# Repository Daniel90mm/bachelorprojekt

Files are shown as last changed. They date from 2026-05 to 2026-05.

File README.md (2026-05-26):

# Bachelorprojekt: Prototype Pulsoximeter

Repository til bachelorprojektets notebooks, måledata, referencedokumenter
og KiCad-hardwaredesign for en prototypisk pulsoximeter til ikke-invasiv
måling af arteriel iltmætning (SpO₂).

Systemet bruger to multipleksede LED'er ved 660 nm og 940 nm, en
Hamamatsu S1223 fotodiode og en analog signalkæde med transimpedans-
forstærker, andenordens Sallen-Key lavpasfilter og et ikke-inverterende
gain-trin. Det optiske interface er en modulær 3D-printet fingerklemme,
og signalindsamling og -behandling håndteres af en Analog Discovery 3
og en Python-pipeline baseret på ratio-of-ratios-metoden.

Den fulde rapport ligger som [thesis.pdf](thesis.pdf).

## Resultater (live demo)

- HR: (51.7 ± 0.3) BPM
- SpO₂: (95.8 ± 1.5) %: proof of concept, ikke klinisk kalibreret
- LED-bølgelængder: 664.99 nm (FWHM 18.30 nm) og 951.79 nm (FWHM 27.25 nm)

## Struktur

- [notebooks/](notebooks/): Jupyter-notebooks til analyse, plots, målinger og kalibrering.
- [data/](data/): måledata, kalibreringstabeller, livemålinger og genererede plots.
- [docs/](docs/): diagrammer og instrumentkalibrering brugt til dokumentation.
- [hardware/kicad/](hardware/kicad/): KiCad-printprojekt og produktionsfiler.
- [references/](references/): datablade og artikler brugt som projektreferencer.
- [thesis.pdf](thesis.pdf): den endelige rapport.

## Vigtige filer

- [notebooks/filtre.ipynb](notebooks/filtre.ipynb): Bode-analyse af LPF- og HPF-trin.
- [notebooks/plots.ipynb](notebooks/plots.ipynb): spektrale plots, LED-sammenligninger og projektfigurer.
- [notebooks/optokæde.ipynb](notebooks/optokæde.ipynb): simulering af hele optokæden fra LED til signal.
- [notebooks/hyperspektral_pixelanalyse.ipynb](notebooks/hyperspektral_pixelanalyse.ipynb): pixelanalyse af hyperspektrale .tif-billeder.
- [notebooks/spektrometer.ipynb](notebooks/spektrometer.ipynb): spektrometeranalyse.
- [notebooks/lineær_stage_kalibrering.ipynb](notebooks/lineær_stage_kalibrering.ipynb): kalibrering af lineær stage.
- [live_pulsoximeter_måling.py](live_pulsoximeter_måling.py): selvstændig liveprototype til måling af HR og SpO₂.
- [plot_pulsoximeter_målinger.py](plot_pulsoximeter_målinger.py): genererer rapportplots fra livemålingerne.
- [data/live/](data/live/): livemålinger brugt til rapportens demonstrationsplots.
- [data/calibration/](data/calibration/): kalibreringsdata og rå Bode-målinger.
- [data/plots/](data/plots/): eksportklare figurer til rapport og præsentation.
- [hardware/kicad/](hardware/kicad/): kredsløbsdiagram, PCB-layout og produktionsfiler.
- [references/datasheets/](references/datasheets/): datablade for centrale komponenter.

## Krav og installation

- Python 3.10 eller nyere.
- Digilent WaveForms SDK installeret (kræves af `dwfpy` for at tale med Discovery 3).

```bash
python -m venv .venv
source .venv/bin/activate    # Windows: .venv\Scripts\activate
pip install -r requirements.txt
```

## Live pulsoximeter

Kør livevisning med popout-plot:

```bash
python live_pulsoximeter_måling.py --cycle-rate 7.41
```

Regenerer rapportplots fra livemålingerne i [data/live/](data/live/):

```bash
python plot_pulsoximeter_målinger.py
```

## Noter

- Lokale editorfiler, Jupyter-cache, KiCad-låse-/historikfiler og genererede backup-zipfiler ignoreres.
- Løse WaveForms-eksporter og rå livemålinger i repo-roden ignoreres.
  Rå kalibreringsmålinger ligger i [data/calibration/](data/calibration/),
  navngivne livemålinger i [data/live/](data/live/), og færdige figurer
  ligger i [data/plots/](data/plots/).

## Licens

MIT: se [LICENSE](LICENSE).

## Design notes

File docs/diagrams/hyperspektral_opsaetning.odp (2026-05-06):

## Hyperspektralt setup, formål og rolle I projekt

- Validere valg af bølgelængder til analogt setup
- Relativt transmitteret intensitet per bølgelængde → pixel intensitet

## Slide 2

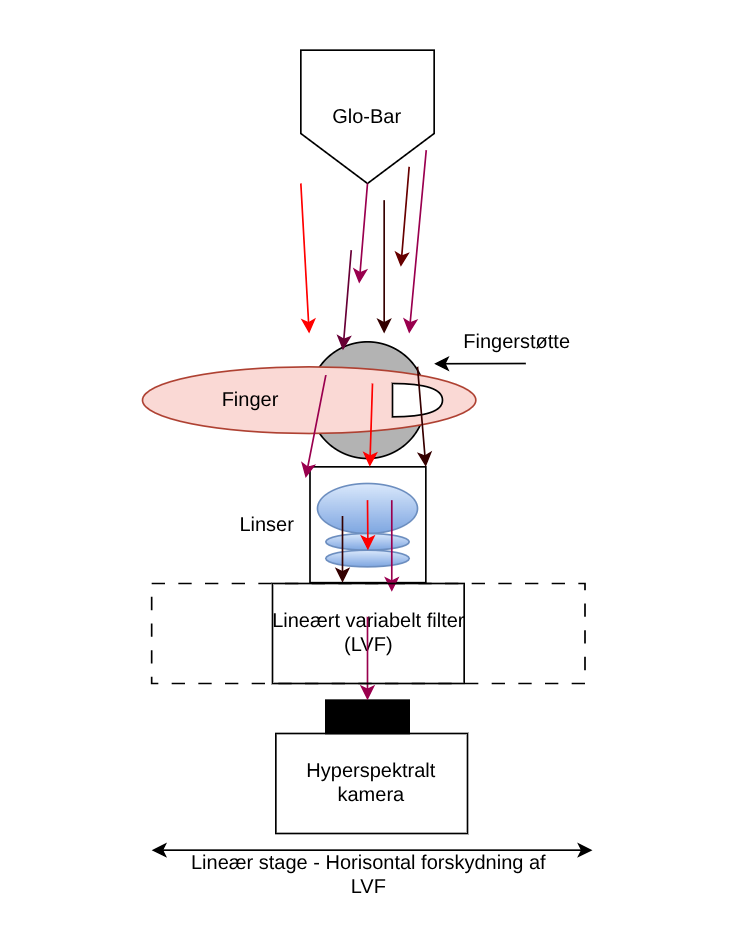
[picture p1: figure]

Glo-Bar:

- Bredbåndet kilde
- Sort legeme spektrum med spektral irradians I NIR(800-1100nm)
- Peak ved mid-IR(1900-2400nm)

LVF, lineært variabelt filter:

- ~800-1100nm
- FWHM skalerer med bølgelængde
- Bandpasser bølgelængder

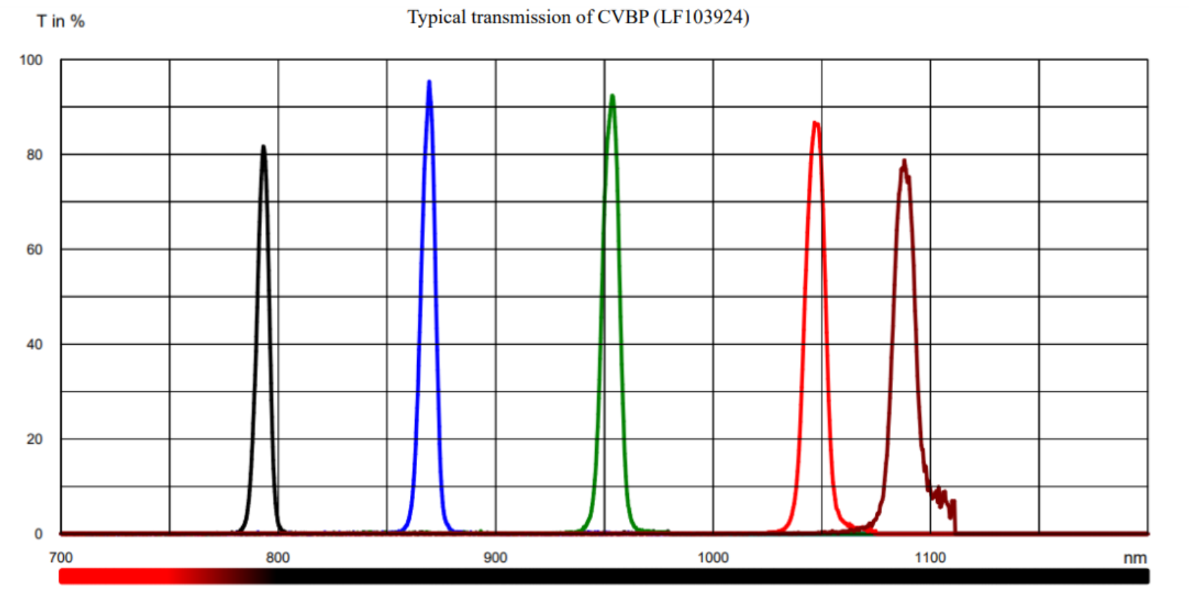
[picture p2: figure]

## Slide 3

- Spredning dominerer over absorption I NIR I væv
- Pga. Spredning, rejser fotoner 4-7 gange længere end fingerafstand d.
  Kvantificeret med DPF (differential pathlength factor)

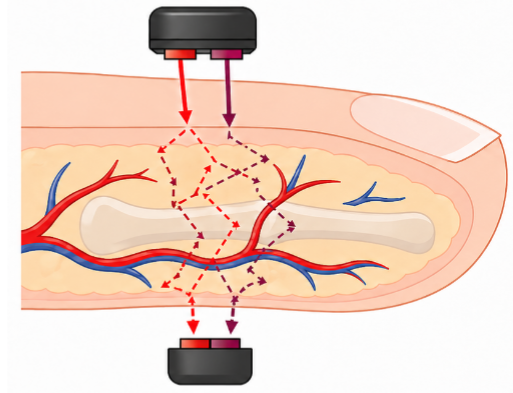
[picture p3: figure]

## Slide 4

Kamera:

- Kvante effektivitet per bølgelængde
- Silicium sensor, NIR variant
- Længere integrationstid → Flere fotoner opsamles → Højere pixelværdi indtil mættelse
- Foton → elektron hul-par → ADC “fyldes op” → Hvidere pixel I kamera feed
- Kameraet skelner ikke mellem bølgelængder, det gør LVF
- Mørkemåling tages med fikseret interesseregion (ROI) og integrationstid
- Faktisk måling tages med samme ROI & integrationstid
- Median udregnes af mørkemåling og faktisk måling
- Korrigeret_måling(ƛ) = median[måling(ƛ)] – median[mørkemåling(ƛ)]
- Hyperspekt_output(ƛ) = Korrigeret_måling(ƛ) / integrationstid

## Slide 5

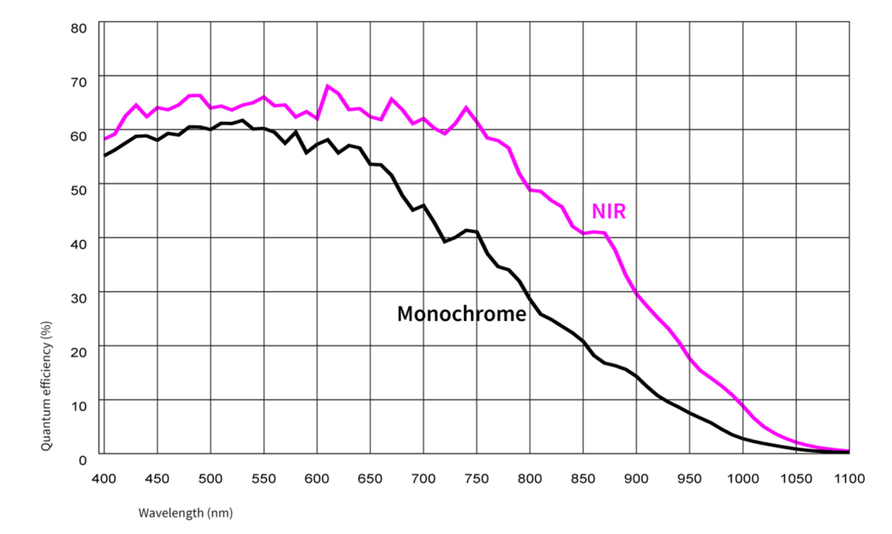
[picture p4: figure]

~47%

~22%

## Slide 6

Resultater

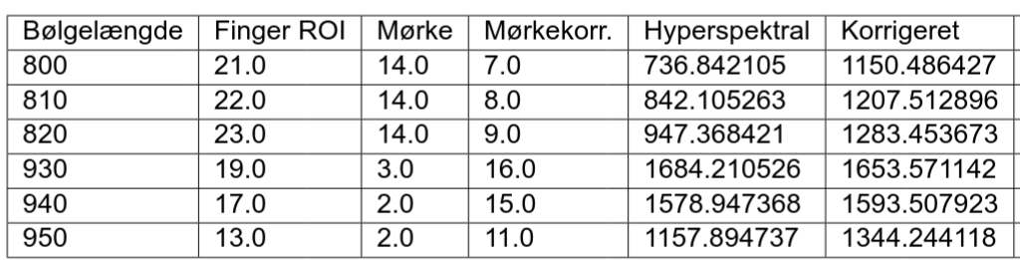
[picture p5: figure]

Korrigeret for datasheet specs med diverse
attenuationer per bølgelængde

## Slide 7

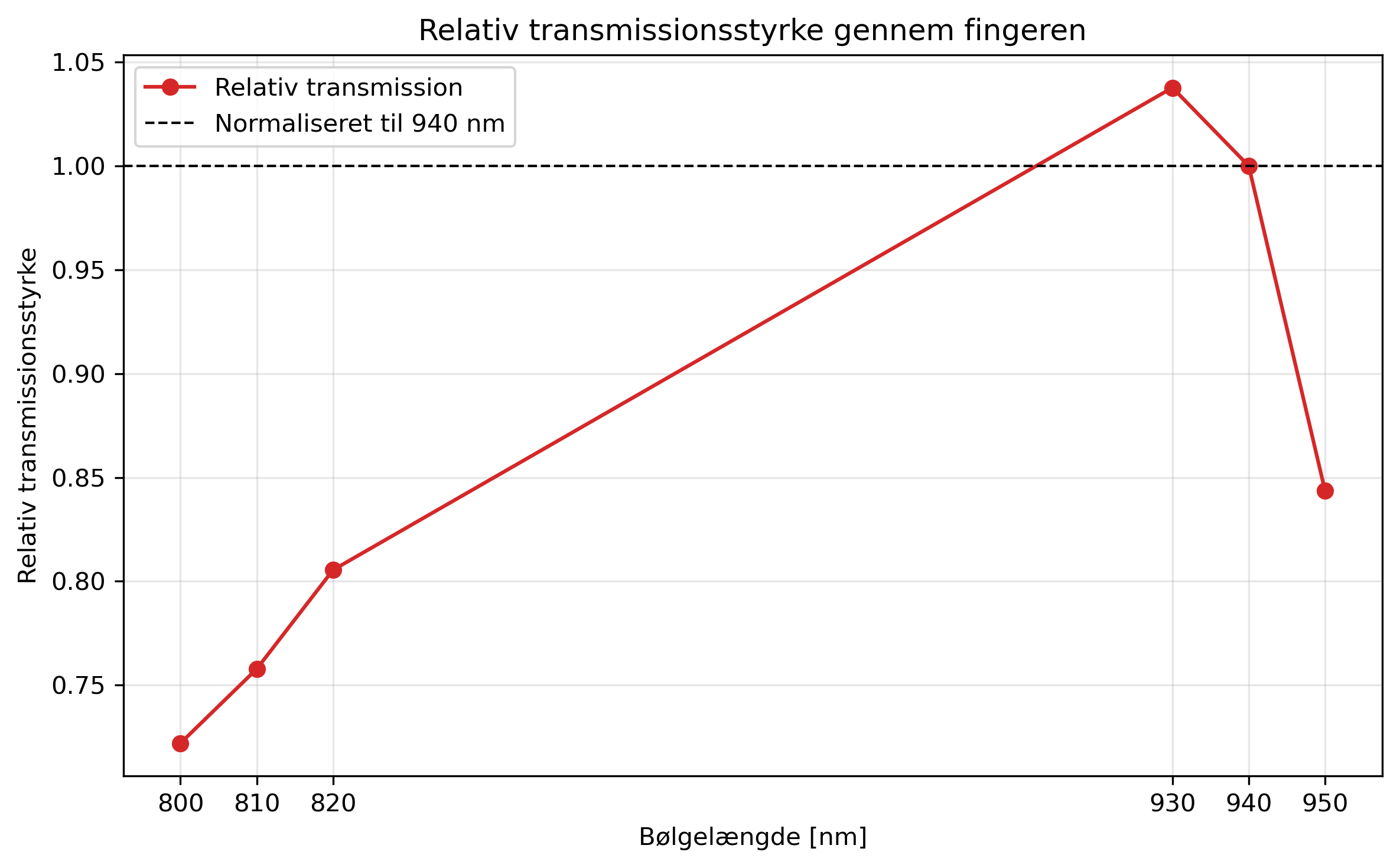
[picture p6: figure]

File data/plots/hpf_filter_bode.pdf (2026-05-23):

### Højpasfilter: målt frekvensrespons

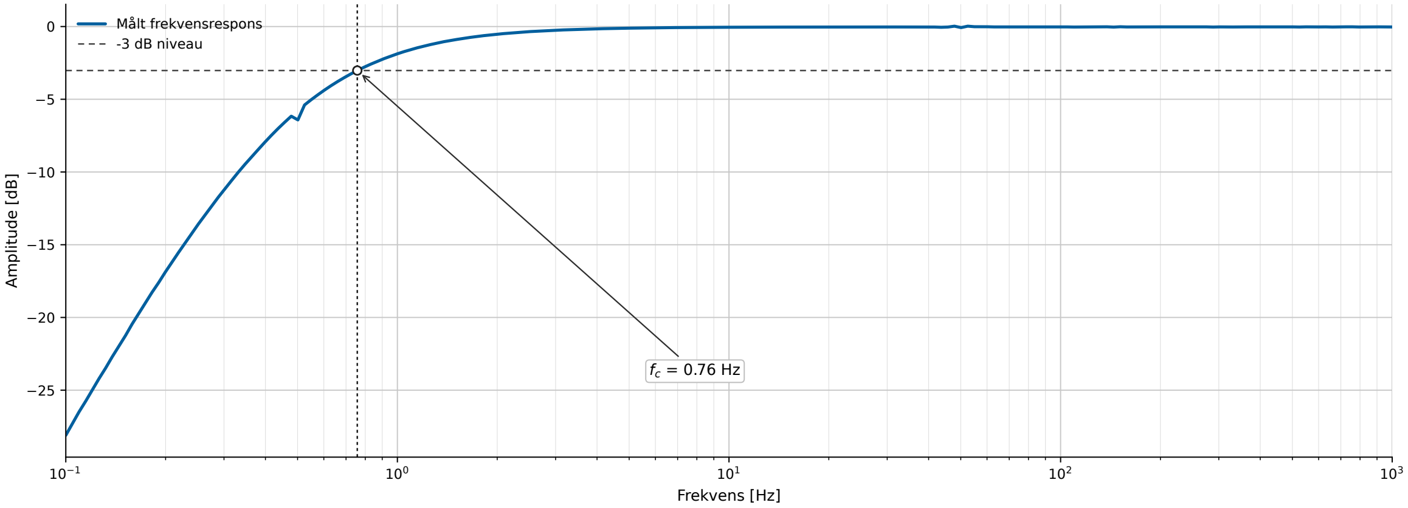
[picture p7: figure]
Frekvens [Hz]; Amplitude [dB]; Målt frekvensrespons -3 dB niveau

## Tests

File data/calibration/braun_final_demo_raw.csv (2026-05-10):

v_660 | v_940 | v_dark | v_660_korr | v_940_korr | t_s
3.8659478658159014 | 4.352355155628666 | 0.009007681549563657 | 3.856940184266338 | 4.343347474079102 | 0.5520272519788705
3.9043274512252446 | 4.376674222711291 | 0.009022347901023764 | 3.8953051033242208 | 4.367651874810267 | 0.7000380189856514
4.001045270019376 | 4.432150261199594 | 0.008407489320580708 | 3.9926377806987956 | 4.423742771879014 | 0.9922793039877433
3.8210158058465344 | 4.293303911926739 | 0.010386318586813936 | 3.8106294872597206 | 4.282917593339925 | 1.2256143789854832
3.8156682284680024 | 4.300710419414095 | 0.010613082944004848 | 3.8050551455239976 | 4.29009733647009 | 1.4984336989873555
3.882745350961253 | 4.345723708406934 | 0.010631133838109605 | 3.8721142171231433 | 4.335092574568824 | 1.7334016989916563
3.96838781804124 | 4.394711578645461 | 0.010974100826099856 | 3.95741371721514 | 4.383737477819362 | 1.9846574179828167
4.0455632876052166 | 4.435411832128148 | 0.011618292109463137 | 4.033944995495753 | 4.423793540018685 | 2.2000456949754152
3.8901349357353854 | 4.30695038786993 | 0.010517187569073366 | 3.879617748166312 | 4.296433200300856 | 2.443767716991715
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

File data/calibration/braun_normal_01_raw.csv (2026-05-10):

v_660 | v_940 | v_dark | v_660_korr | v_940_korr | t_s
2.846700745648549 | 3.1698681591676507 | 0.03204400696986929 | 2.81465673867868 | 3.1378241521977817 | 0.5542634270095732
2.88233659515397 | 3.190915501693789 | 0.03210380055659126 | 2.8502327945973787 | 3.1588117011371977 | 0.703124221006874
2.69107721848621 | 3.042041880745746 | 0.03134227846154713 | 2.659734940024663 | 3.0106996022841988 | 0.985604036017321
2.731528143994073 | 3.078389612387423 | 0.031414482037966124 | 2.700113661956107 | 3.0469751303494568 | 1.234539452008903
2.804102891923102 | 3.1245773376779518 | 0.031944727052293155 | 2.7721581648708087 | 3.0926326106256585 | 1.4933193490142003
2.8651419903383144 | 3.161053681940125 | 0.03186913893322952 | 2.8332728514050847 | 3.1291845430068954 | 1.711352947022533
2.93088785939134 | 3.2016557836861157 | 0.032196311388878116 | 2.898691548002462 | 3.1694594722972376 | 1.942395899008261
2.8414862936140395 | 3.097546123756089 | 0.032556201090091566 | 2.8089300925239478 | 3.064989922665997 | 2.157126000005519
2.813807503866168 | 3.104280235438042 | 0.03220872137857513 | 2.7815987824875927 | 3.0720715140594668 | 2.3972083250118885
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

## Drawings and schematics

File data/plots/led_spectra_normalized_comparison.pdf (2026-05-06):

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

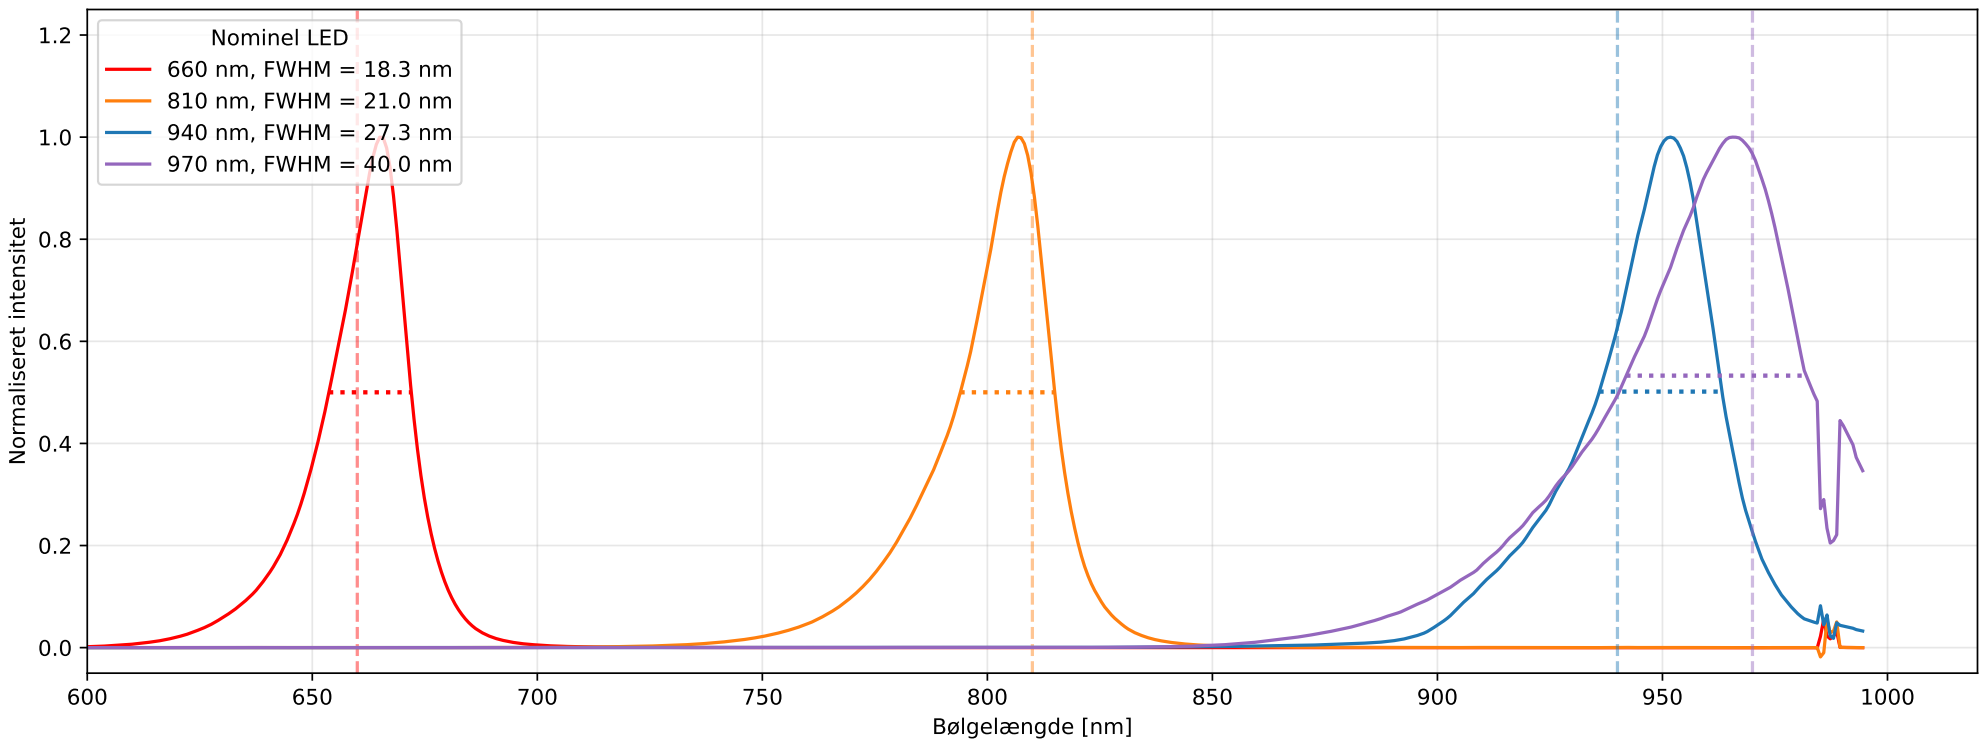
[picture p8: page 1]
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

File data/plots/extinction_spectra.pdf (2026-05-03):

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

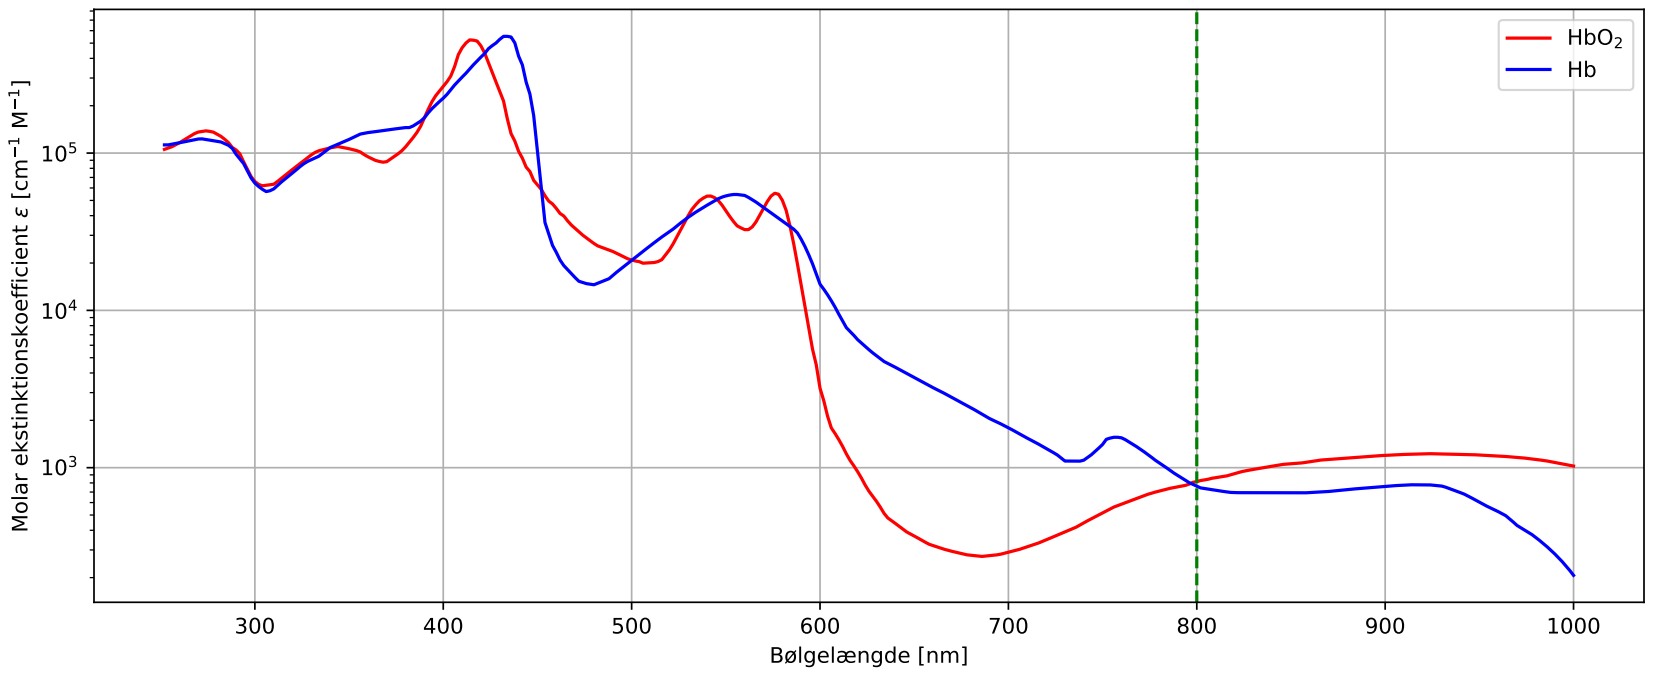
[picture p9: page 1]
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

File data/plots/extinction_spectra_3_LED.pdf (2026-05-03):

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

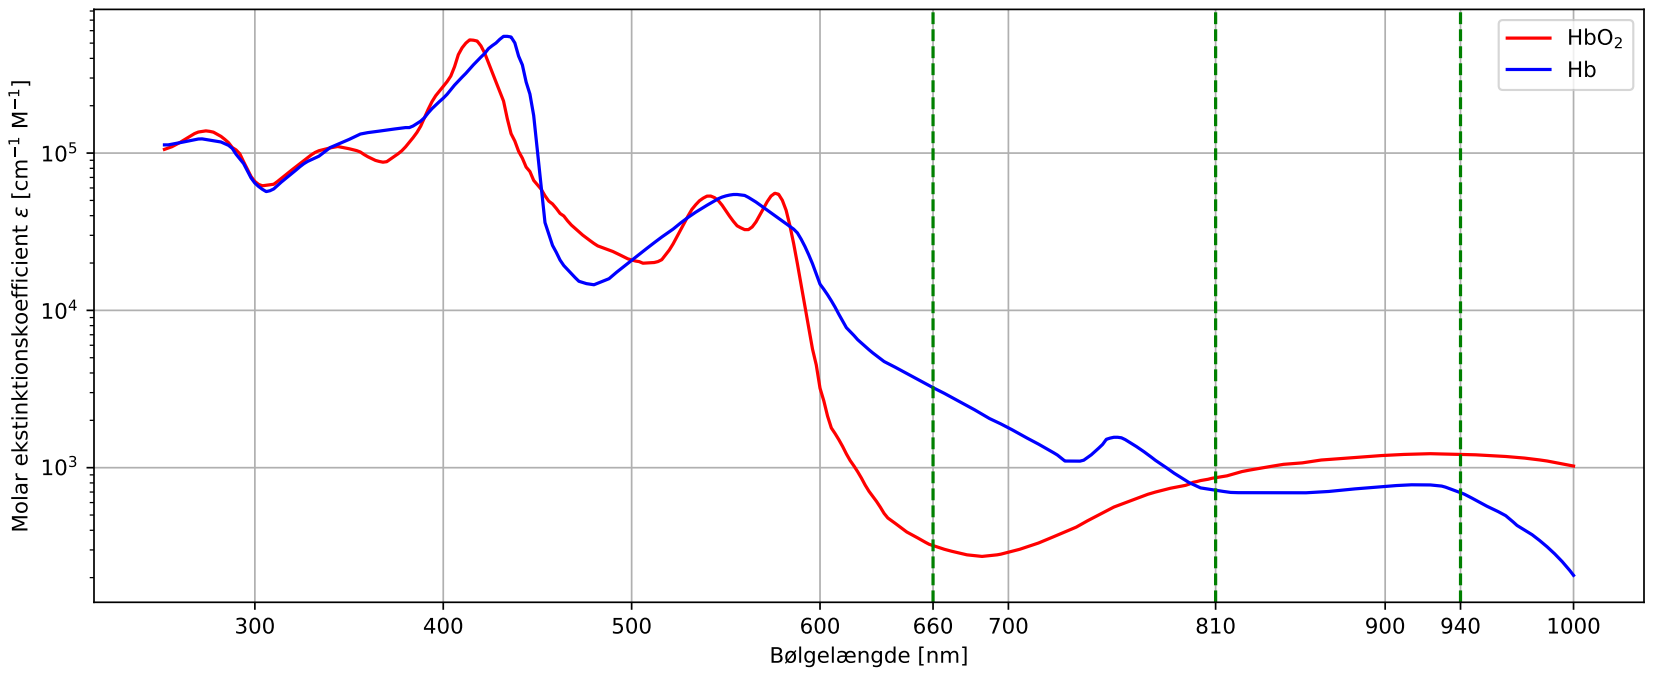
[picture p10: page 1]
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

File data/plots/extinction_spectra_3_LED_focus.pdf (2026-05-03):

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

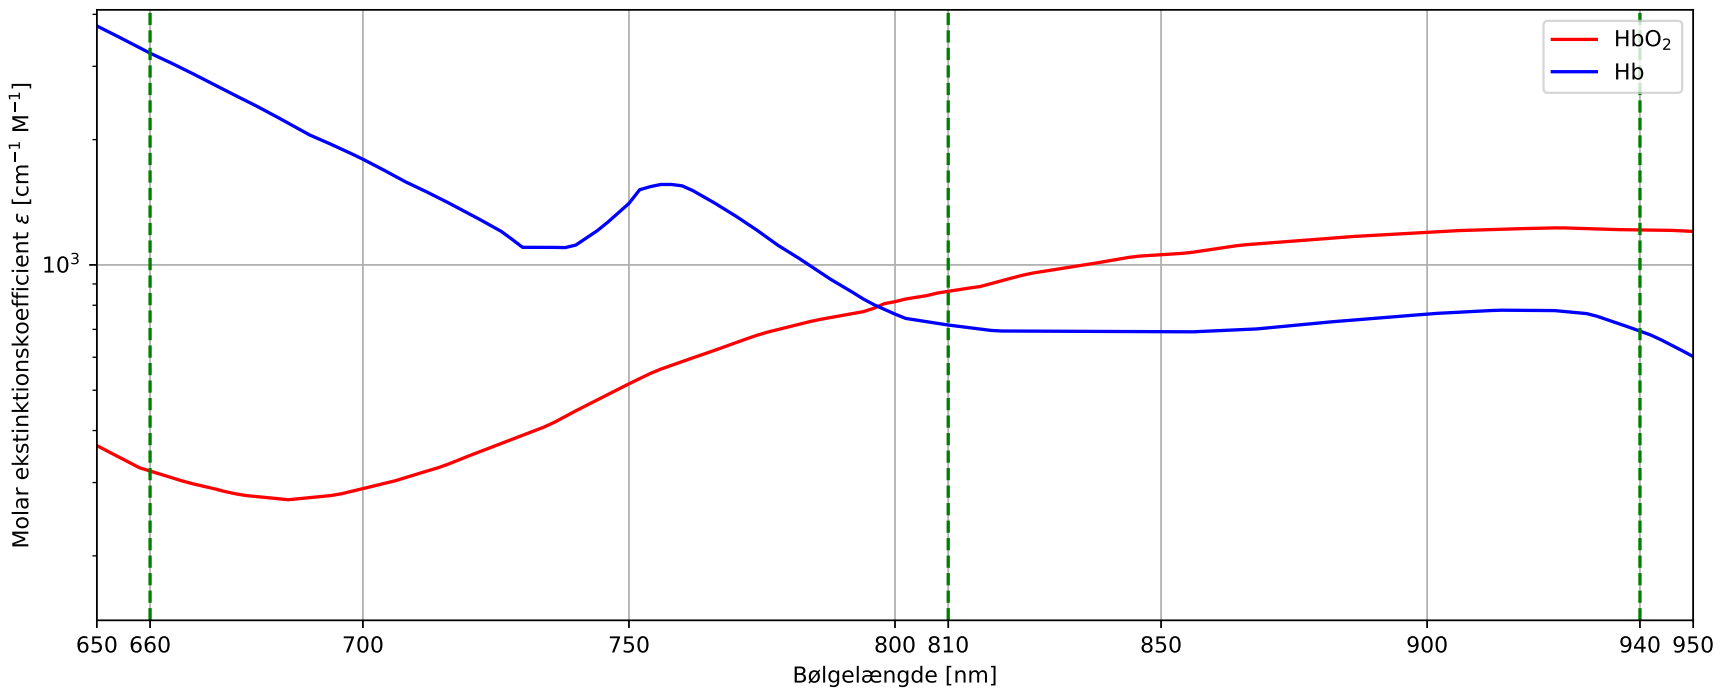
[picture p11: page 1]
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

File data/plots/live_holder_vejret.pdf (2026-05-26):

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

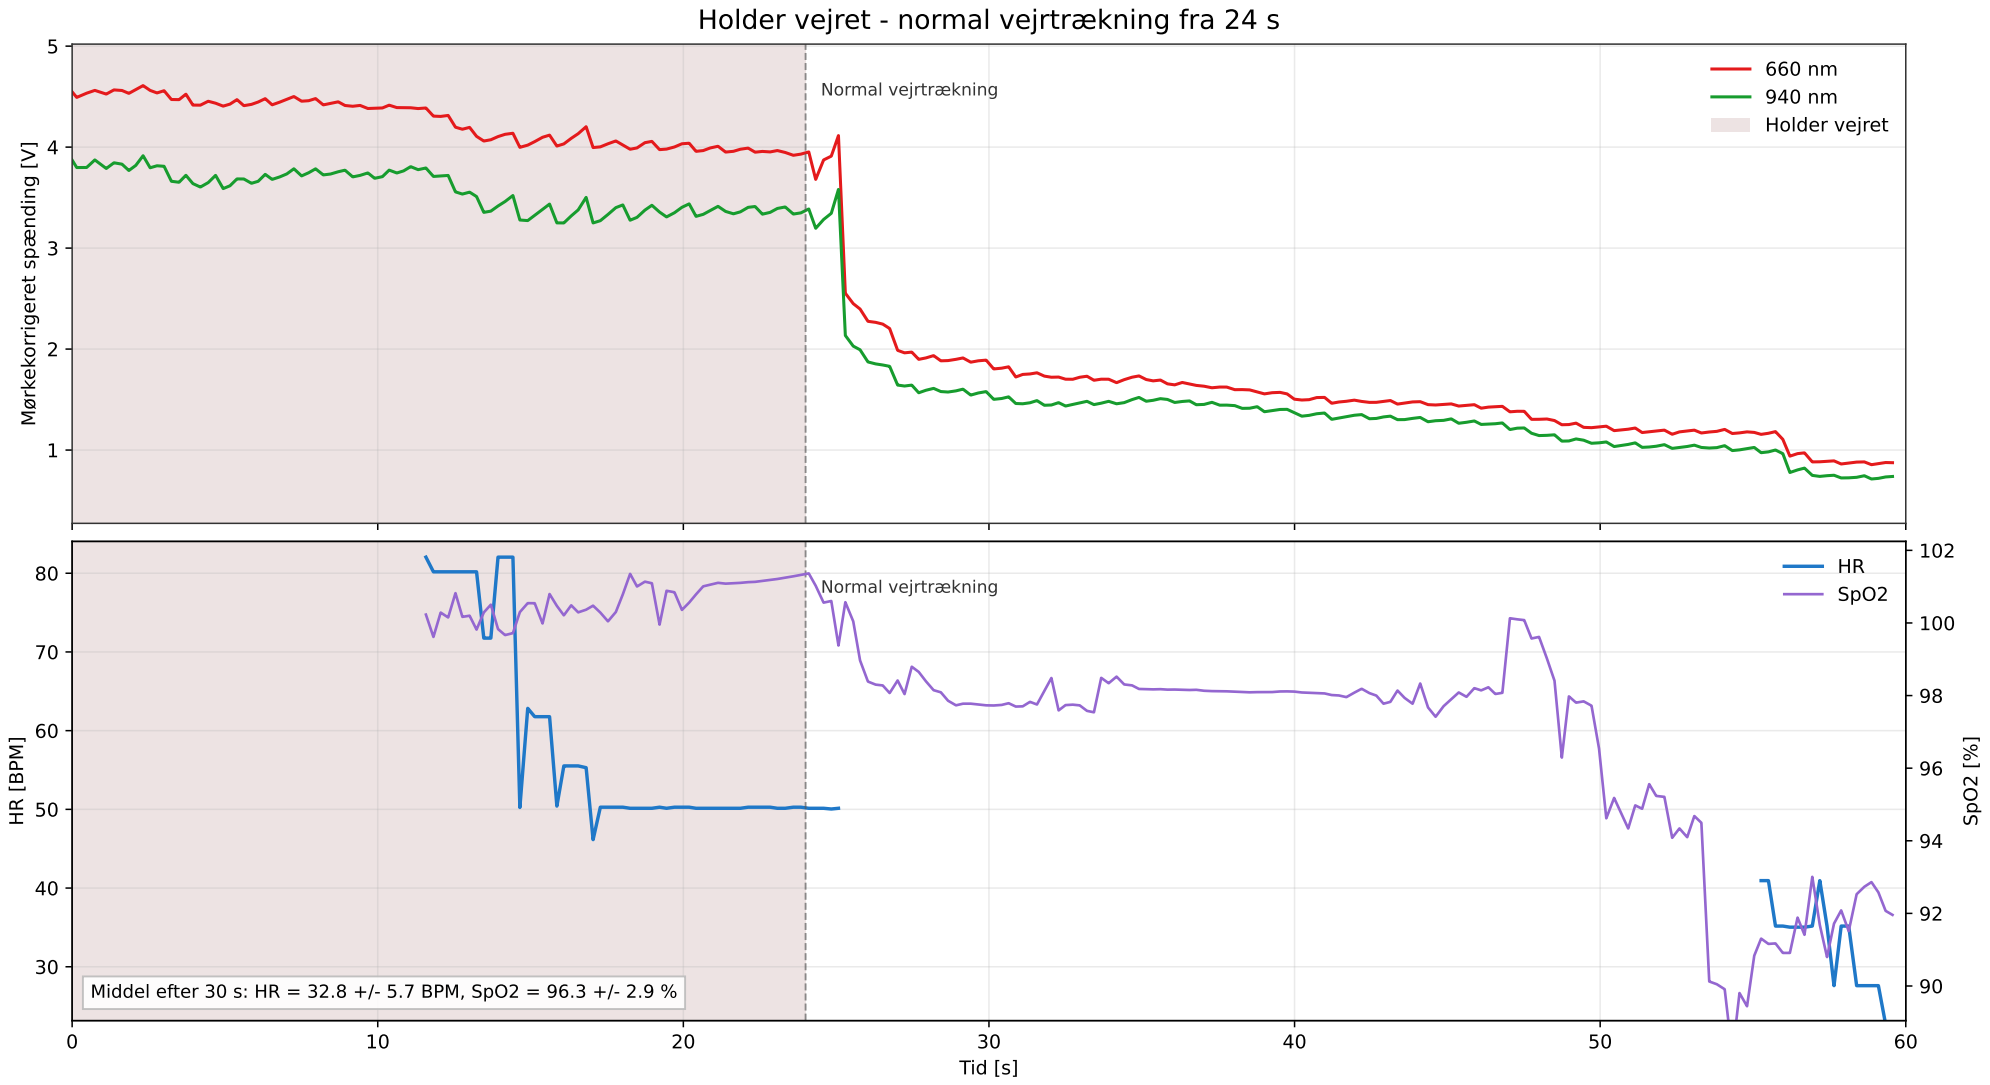
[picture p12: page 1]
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

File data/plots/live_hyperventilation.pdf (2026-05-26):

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

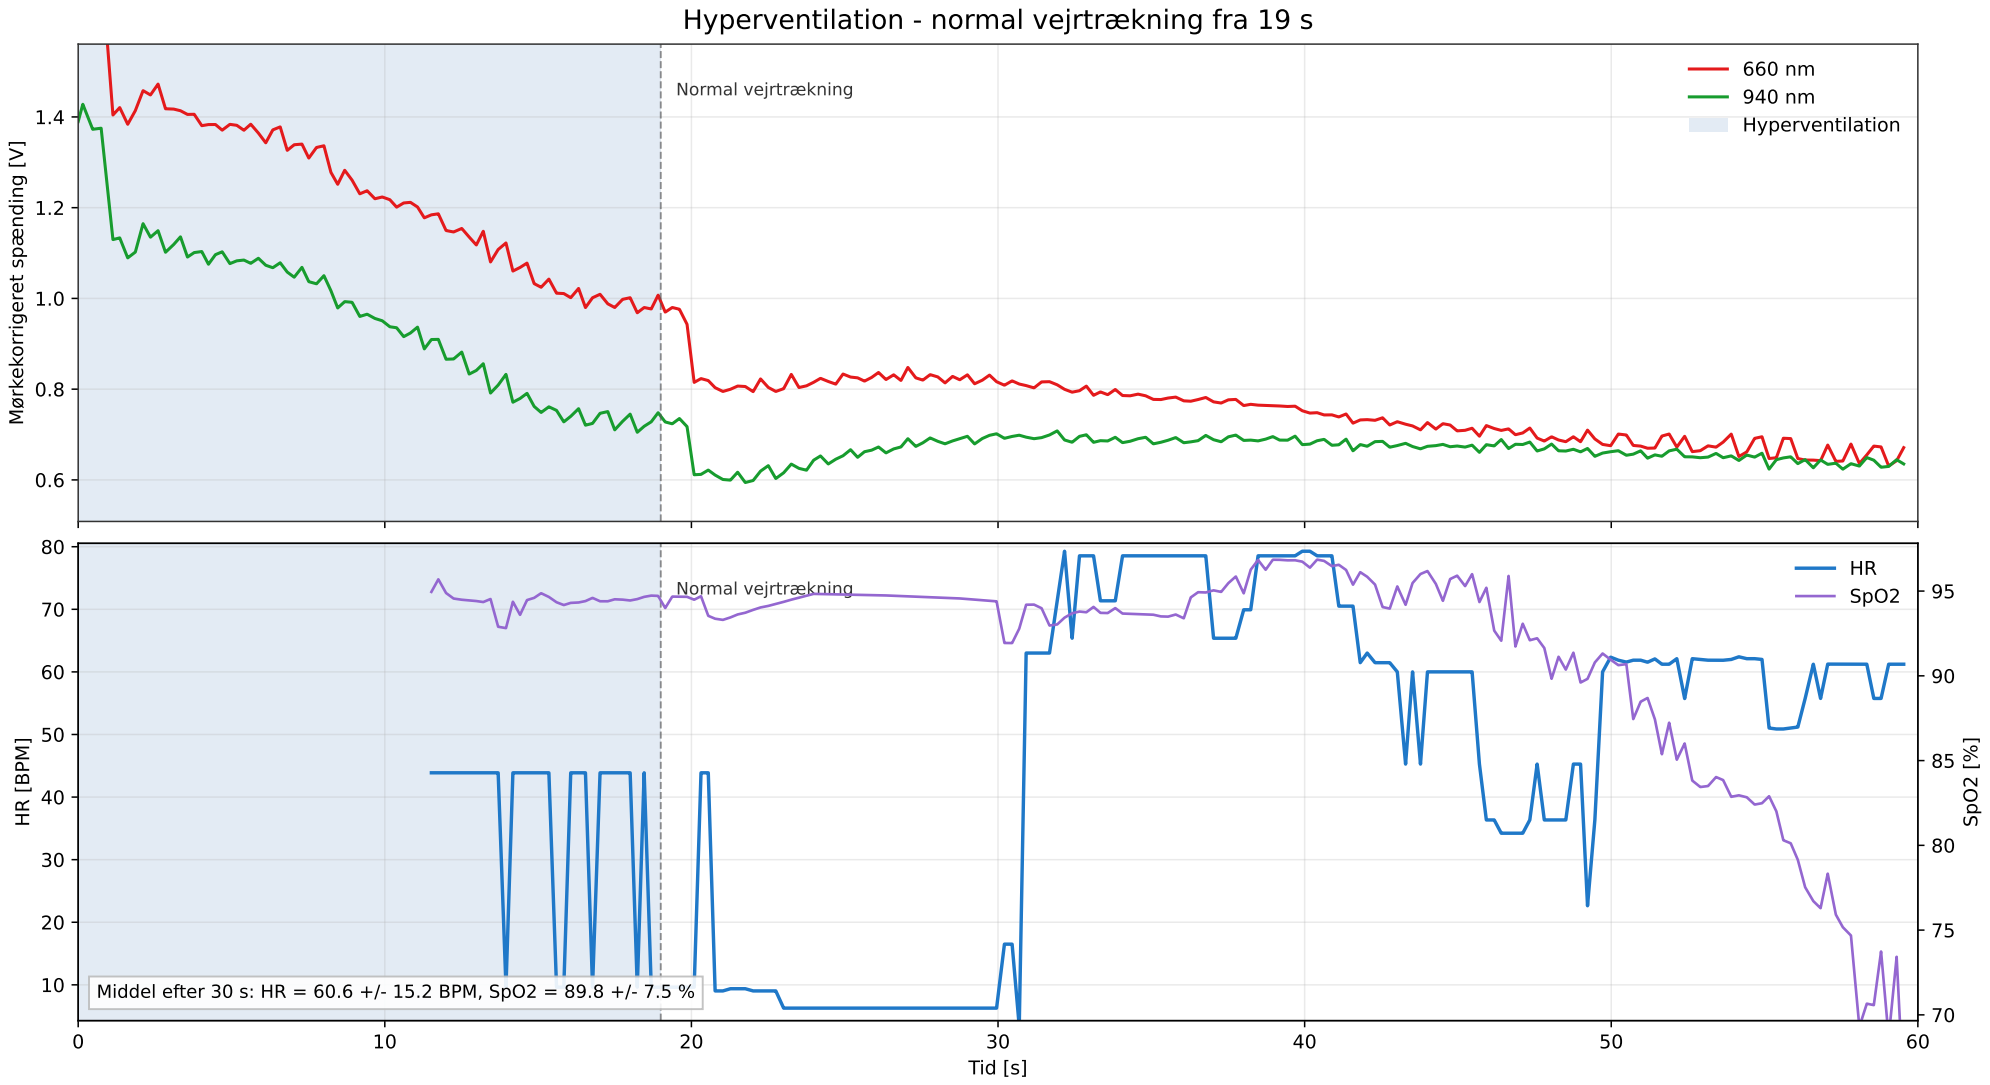
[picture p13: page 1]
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

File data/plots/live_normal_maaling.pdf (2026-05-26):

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

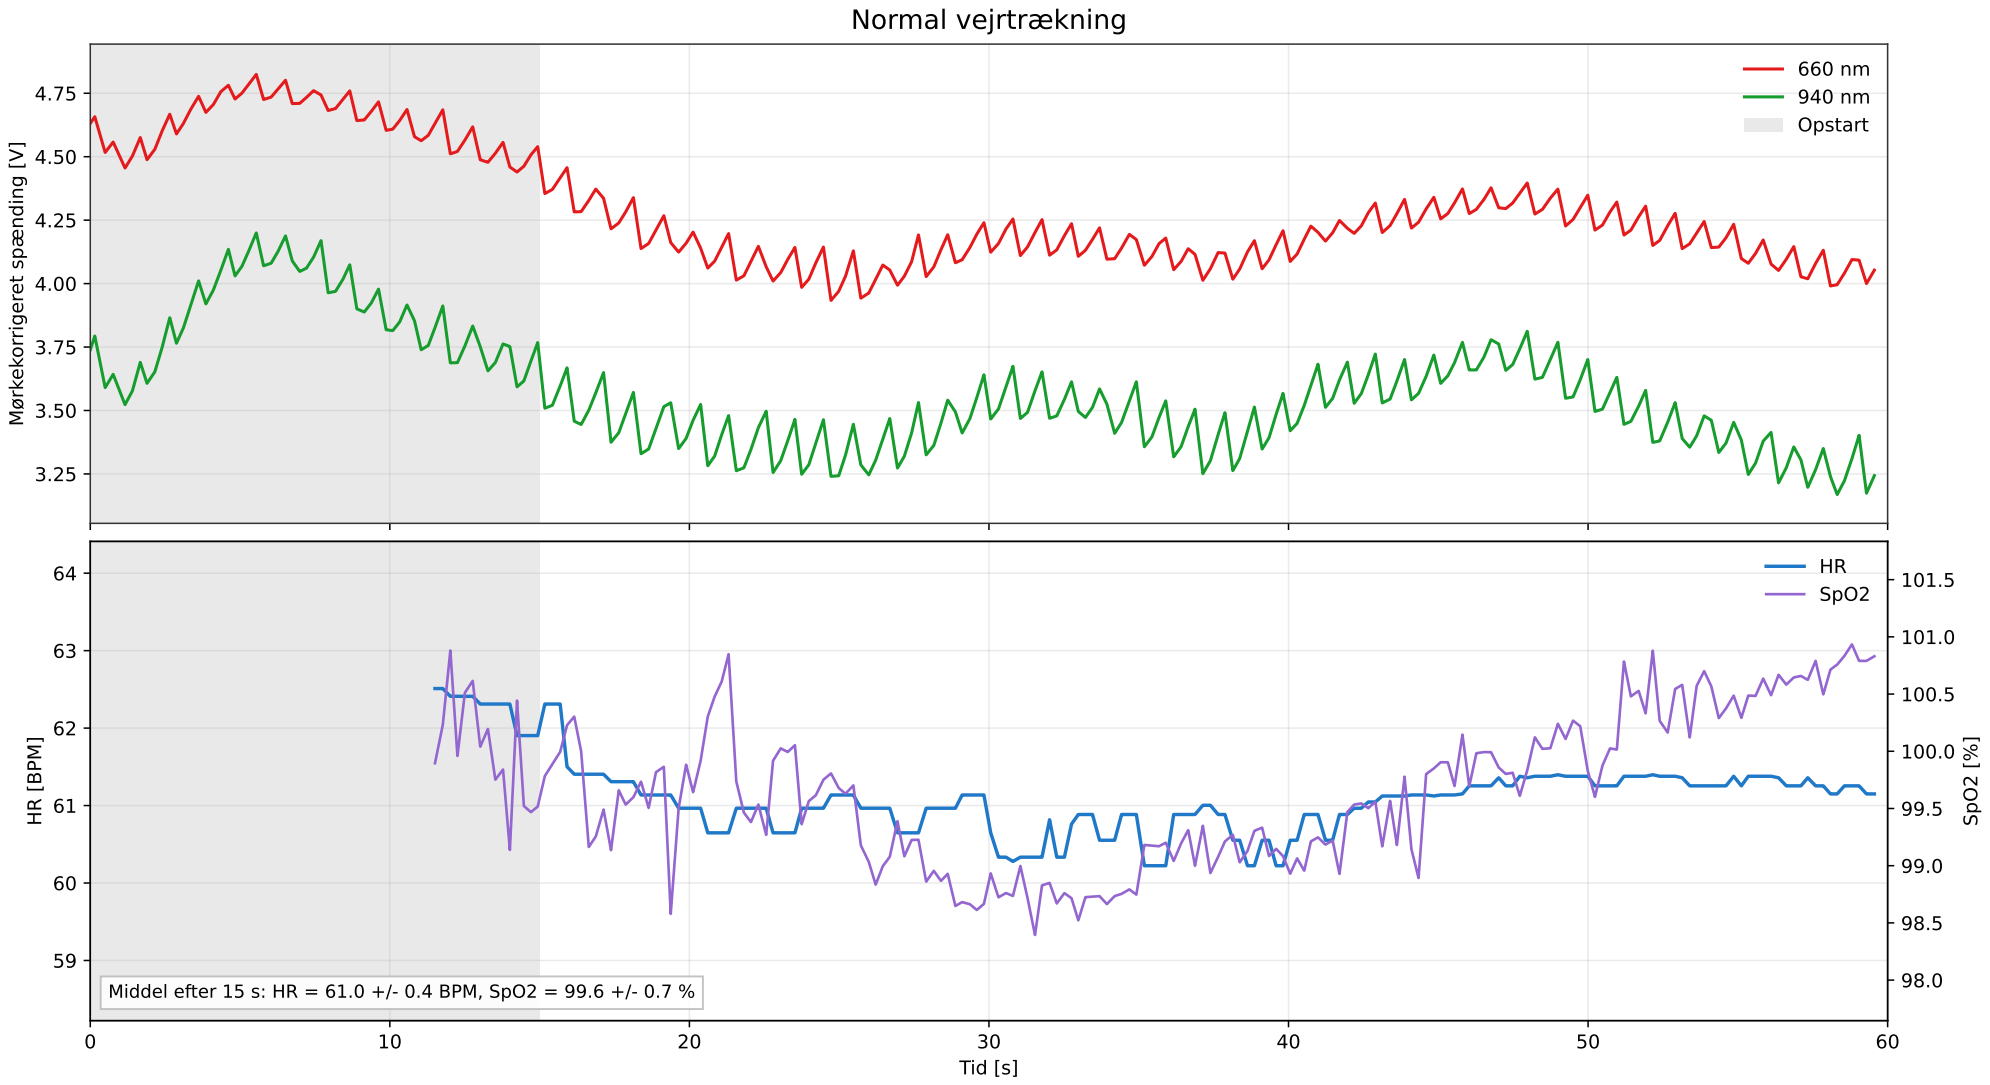
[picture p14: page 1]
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

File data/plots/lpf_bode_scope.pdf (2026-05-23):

−100

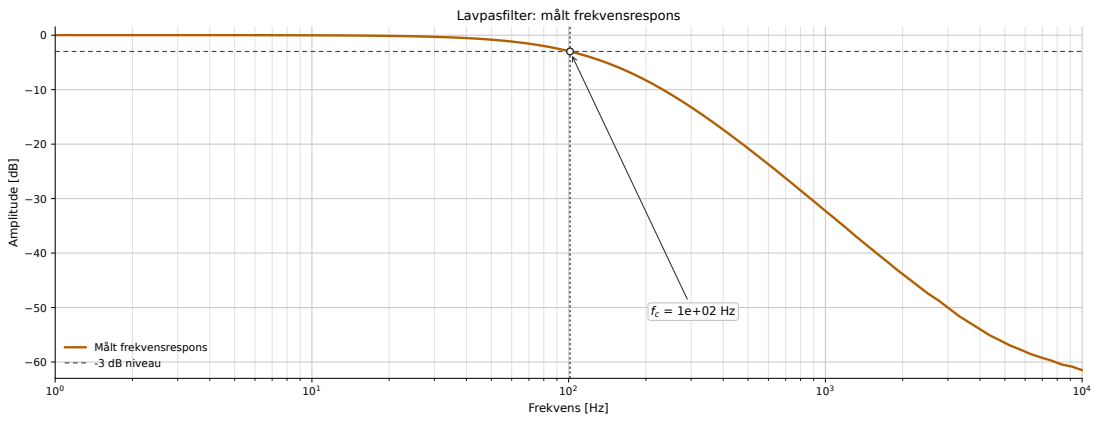
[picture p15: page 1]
Frekvens [Hz]; Amplitude [dB]; Målt frekvensrespons -3 dB niveau

Lavpasfilter: målt frekvensrespons

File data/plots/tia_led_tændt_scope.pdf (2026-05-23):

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

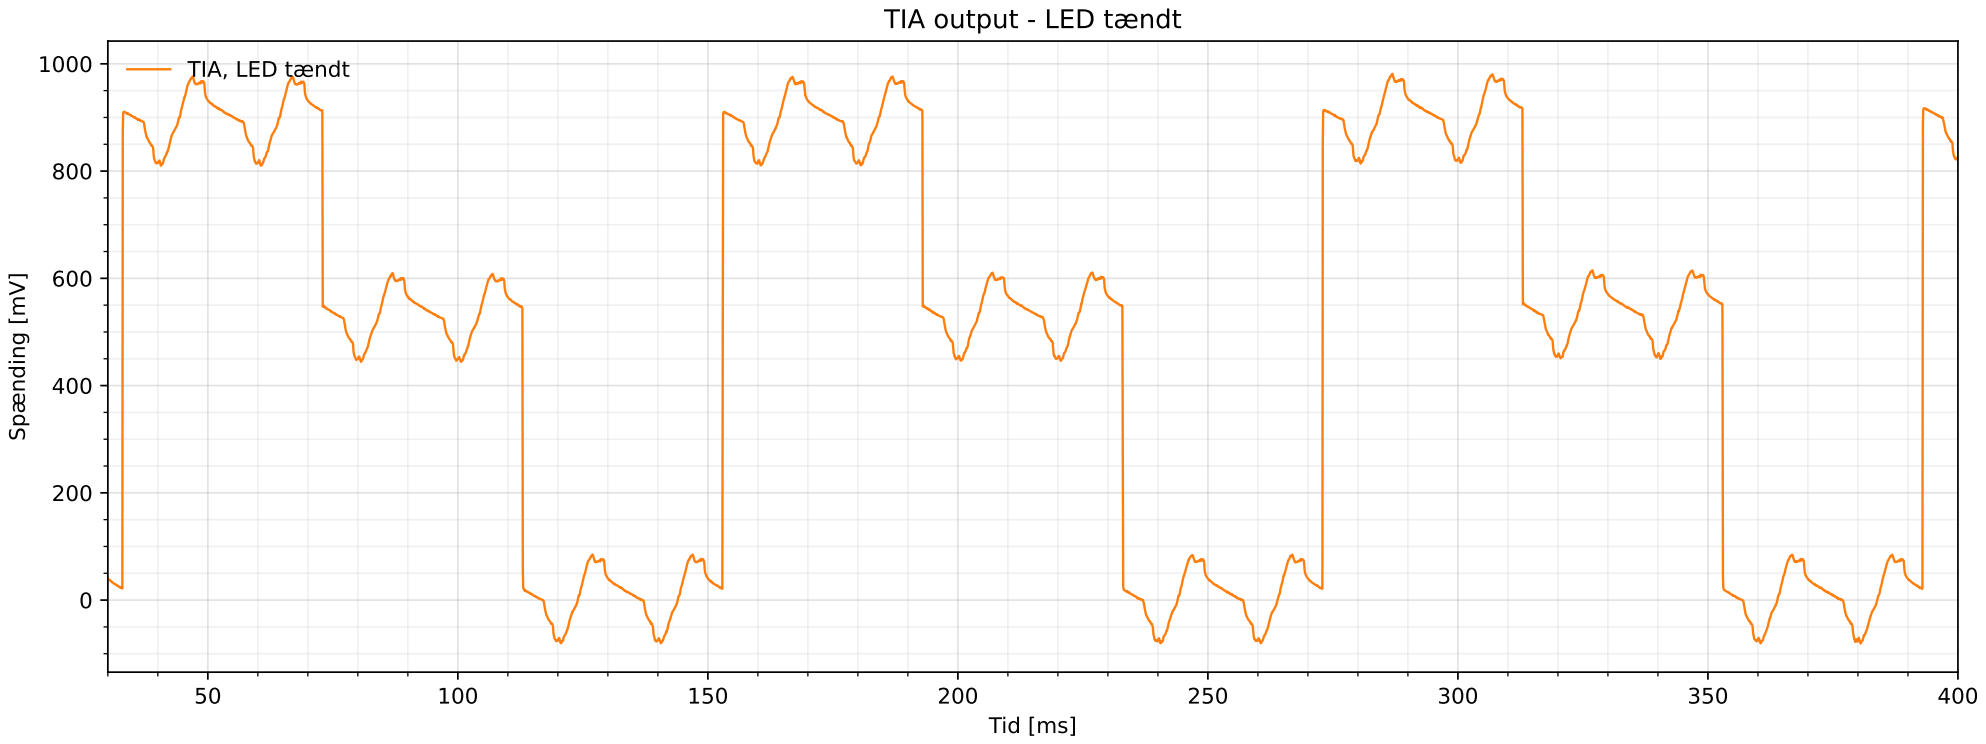
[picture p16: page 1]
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

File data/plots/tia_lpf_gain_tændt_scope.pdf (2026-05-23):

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

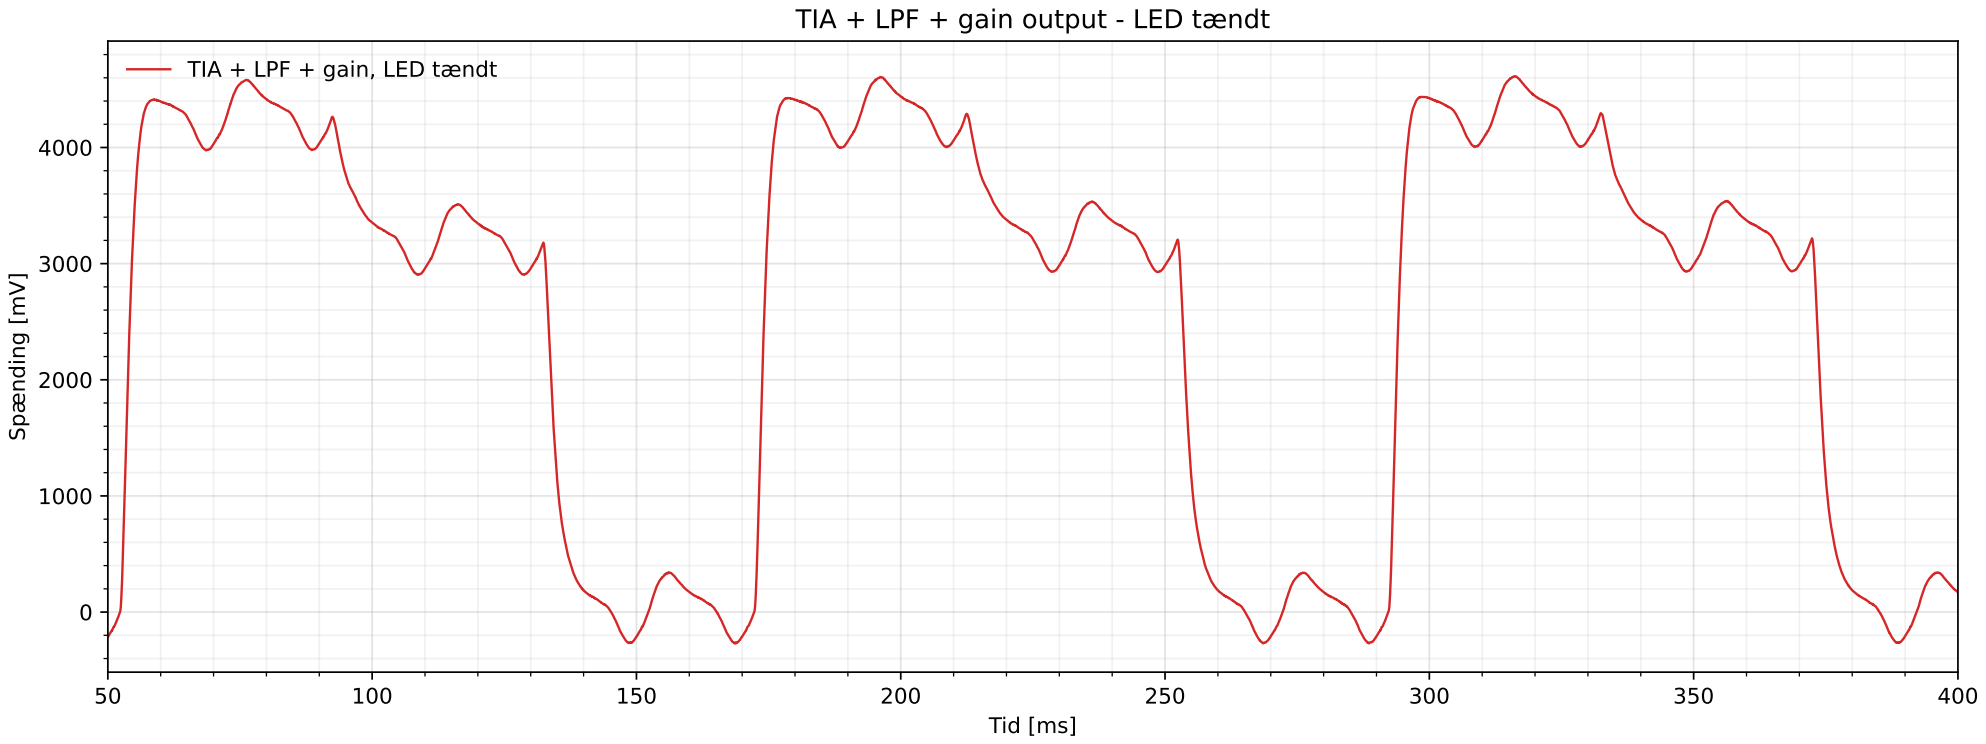
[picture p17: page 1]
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

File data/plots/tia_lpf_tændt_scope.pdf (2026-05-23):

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

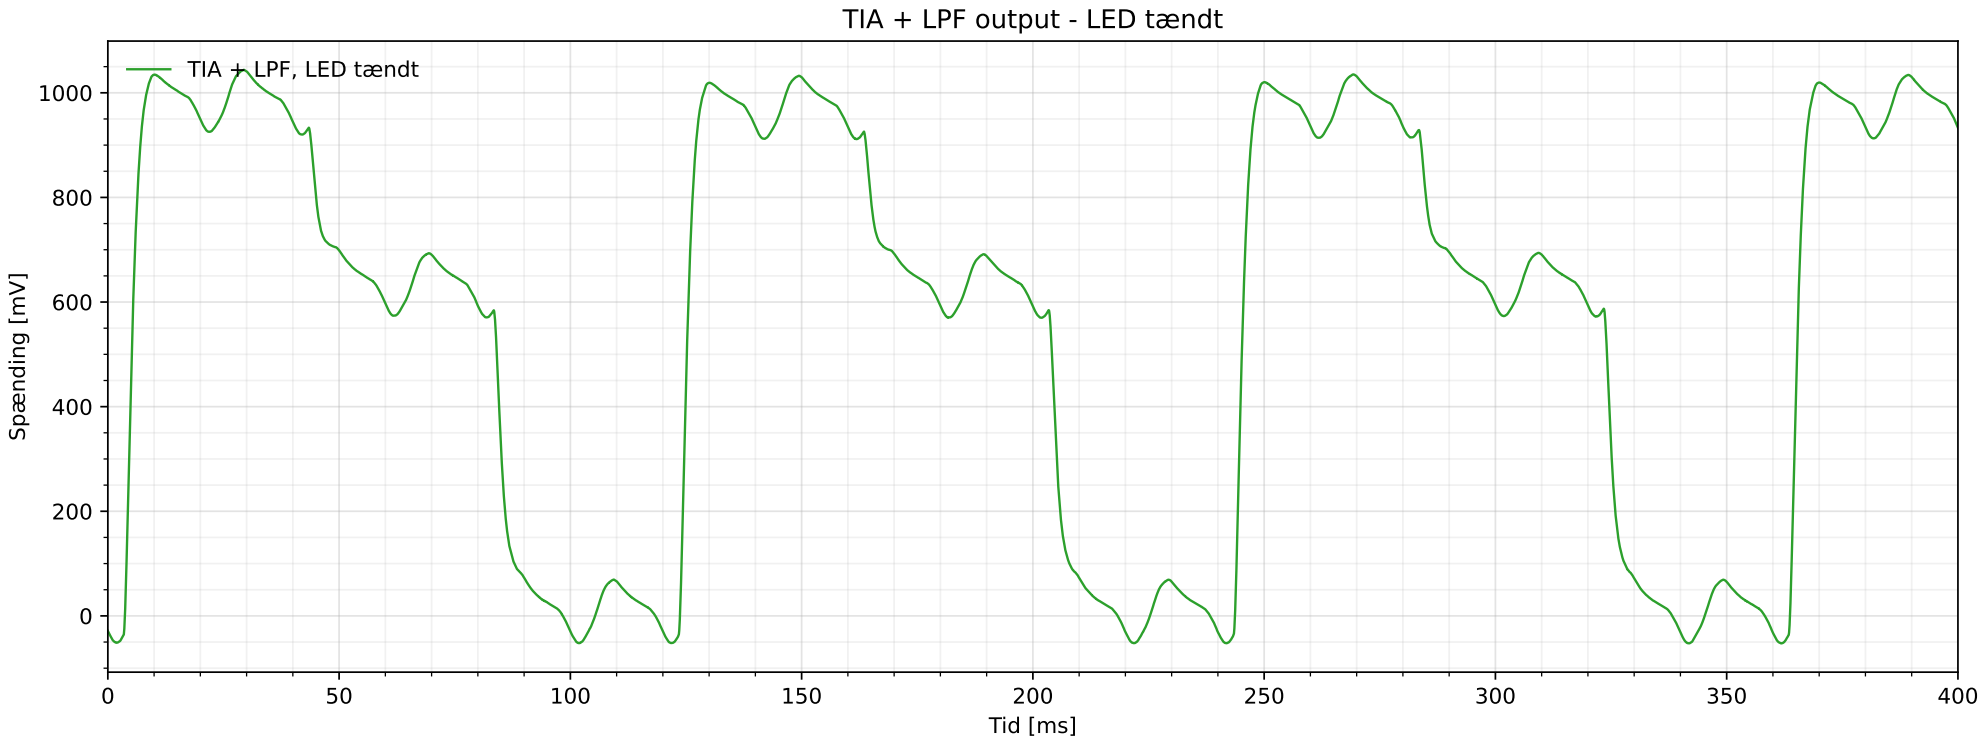
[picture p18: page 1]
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

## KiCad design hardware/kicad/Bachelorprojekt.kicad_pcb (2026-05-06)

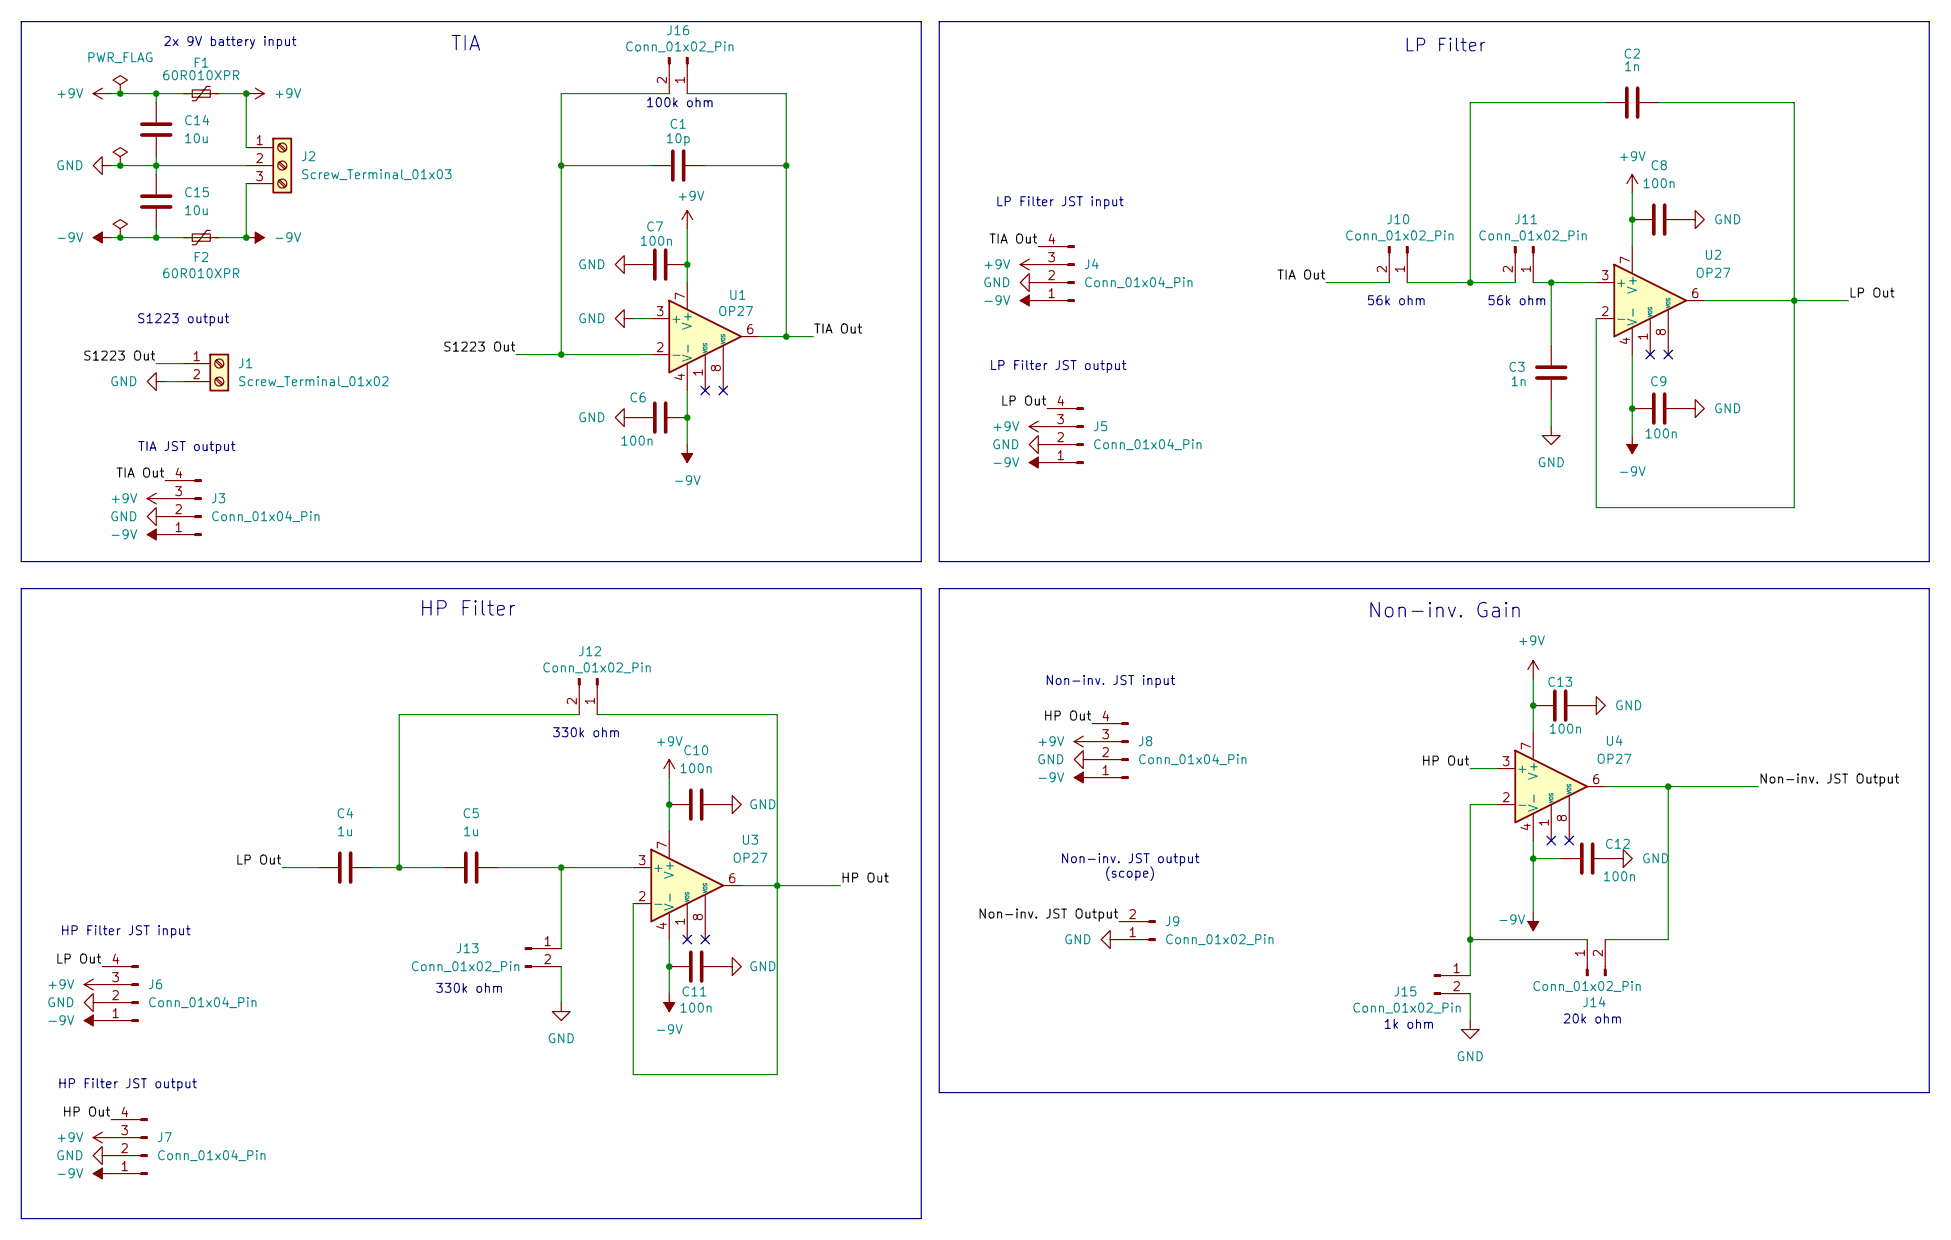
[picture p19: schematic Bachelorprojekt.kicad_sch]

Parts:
C1: 10p; C_Disc_D5.0mm_W2.5mm_P2.50mm
C2, C3: 1n; C_Rect_L7.0mm_W3.5mm_P5.00mm
C4, C5: 1u; C_Rect_L7.2mm_W7.2mm_P5.00mm_FKS2_FKP2_MKS2_MKP2
C6, C7, C8, C9, C10, C11, C12, C13: 100n; C_Rect_L7.0mm_W3.5mm_P5.00mm
C14, C15: 10u; C_Rect_L7.0mm_W4.5mm_P5.00mm
F1, F2: 60R010XPR; Fuse_Bourns_MF-RG300
J1: Screw_Terminal_01x02; TerminalBlock_MaiXu_MX126-5.0-02P_1x02_P5.00mm
J2: Screw_Terminal_01x03; TerminalBlock_MaiXu_MX126-5.0-03P_1x03_P5.00mm
J3, J4, J5, J6, J7, J8: Conn_01x04_Pin; JST_XH_B4B-XH-A_1x04_P2.50mm_Vertical
J9: Conn_01x02_Pin; JST_XH_B2B-XH-A_1x02_P2.50mm_Vertical
J10, J11, J12, J13, J14, J15, J16: Conn_01x02_Pin; PinSocket_1x02_P2.54mm_Vertical
U1, U2, U3, U4: OP27; DIP-8_W7.62mm_Socket

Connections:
+9V: C7.2, C8.1, C10.1, C13.1, C14.1, F1.1, F1.2, J2.1, J3.3, J4.3, J5.3, J6.3, J7.3, J8.3, U1.7 (V+), U2.7 (V+), U3.7 (V+), U4.7 (V+)
-9V: C6.2, C9.1, C11.1, C12.1, C15.2, F2.1, F2.2, J2.3, J3.1, J4.1, J5.1, J6.1, J7.1, J8.1, U1.4 (V-), U2.4 (V-), U3.4 (V-), U4.4 (V-)
/HP Out: J7.4, J8.4, J12.1, U3.2 (-), U3.6, U4.3 (+)
/LP Out: C2.2, C4.1, J5.4, J6.4, U2.2 (-), U2.6
/Non-inv. JST Output: J9.2, J14.2, U4.6
/S1223 Out: C1.1, J1.1, J16.2, U1.2 (-)
/TIA Out: C1.2, J3.4, J4.4, J10.2, J16.1, U1.6
GND: C3.1, C6.1, C7.1, C8.2, C9.2, C10.2, C11.2, C12.2, C13.2, C14.2, C15.1, J1.2, J2.2, J3.2, J4.2, J5.2, J6.2, J7.2, J8.2, J9.1, J13.2, J15.2, U1.3 (+)
unnamed: C2.1, J10.1, J11.2
unnamed: C3.2, J11.1, U2.3 (+)
unnamed: C4.2, C5.1, J12.2
unnamed: C5.2, J13.1, U3.3 (+)
unnamed: J14.1, J15.1, U4.2 (-)

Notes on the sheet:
1k ohm
20k ohm
TIA
HP Filter
S1223 output
Non-inv. JST output (scope)
LP Filter JST output
HP Filter JST output
Non-inv. Gain
56k ohm
HP Filter JST input
TIA JST output
Non-inv. JST input
2x 9V battery input
LP Filter
330k ohm
100k ohm
LP Filter JST input

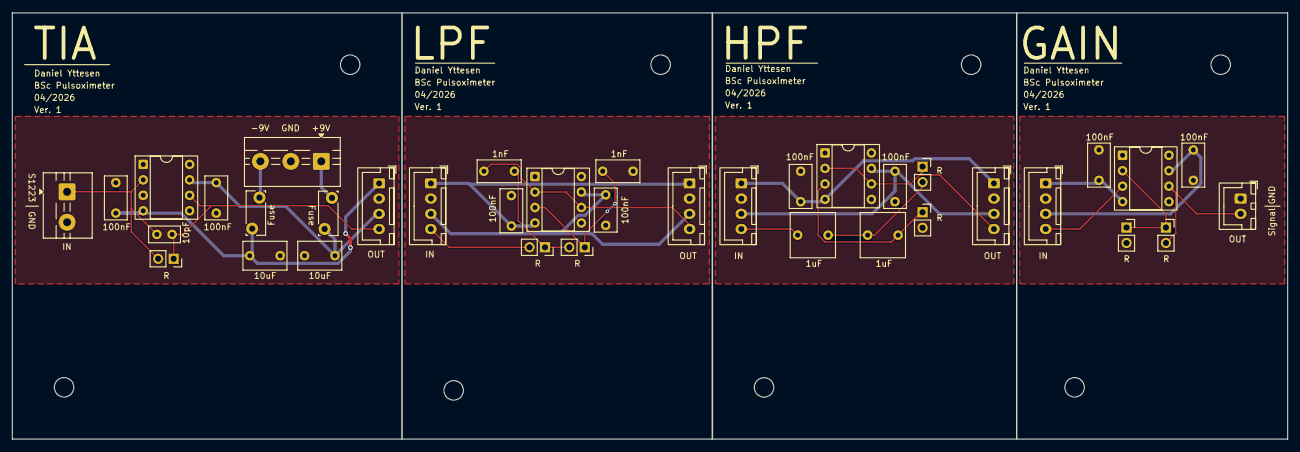
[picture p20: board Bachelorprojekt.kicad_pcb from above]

Board: 2 copper layers, 209.5 x 70.0 mm, 37 parts (0 on the bottom side), 13 nets.

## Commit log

2026-02-04 Tilføjer KiCad kredsløb
    [Bachelorprojekt.kicad_pcb, Bachelorprojekt.kicad_sch]
2026-03-23 marts 23
    [Bachelorprojekt.kicad_sch]
2026-05-03 Strukturer projektfiler og ryd op
    [Bachelorprojekt-B_Cu.gbl, Bachelorprojekt-B_Mask.gbs, Bachelorprojekt-B_Paste.gbp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]
2026-05-06 Organiser projektdata og danske repo-regler
    [Bachelorprojekt.kicad_pcb, ac127-025-ab.xlsx, ac127-050-ab.xlsx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]
2026-05-07 Ensret notebook- og datamappenavne til dansk snake_case
    - Omdøb notebooks til lowercase snake_case med æøå:
    filtre, plots, spektrometer, optokæde, arbejdslog,
    hyperspektral_pixelanalyse, lineær_stage_kalibrering.
    - Omdøb data/raw/daniel/leder/ til lysdioder/ for tydelighed.
    - Slet ubrugt 3Dprint.ipynb.
    - Flyt rå Bode-screenshots fra repo-roden til data/calibration/
    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
2026-05-10 Opdater kalibrering og pulsoximeterdata
    [Bachelorprojekt.kicad_sch, TIA 2.1 Mohm output.csv, TIA_LPF 2.1 Mohm output.csv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]
2026-05-23 Tilføj endelige kalibreringsmålinger og hardwarefiler
    [Bachelorprojekt-LED-driver.kicad_pcb, Bachelorprojekt-LED-driver.kicad_sch, Bachelorprojekt.kicad_sch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]
2026-05-26 Aflever bachelorprojekt: ryd op og tilføj rapport
    - Tilføj thesis.pdf (færdig rapport)
    - Flyt navngivne livemålinger til data/live/ og opdater plot-script
    - Flyt finger_930nm_roi_regioner.png til data/plots/
    - Fjern overskydende _metrics.csv, repeat_*-kalibreringsruns og Præsentation.odp
    - Udvid README med projektoversigt, resultater og links til centrale filer
    - Udvid .gitignore med løse rådata og logs i repo-rod
    [braun_final_demo_metrics.csv, braun_normal_01_metrics.csv, final_data2_metrics.csv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]
